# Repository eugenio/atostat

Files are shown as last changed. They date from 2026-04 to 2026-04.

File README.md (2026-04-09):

# atostat

A modular multichannel potentiostat with bipotentiostat capabilities, designed and built with [atopile](https://atopile.io).

## Key Specifications

- **Current range:** 10 nA to 1 A per channel (8 decades, switched-gain TIA)
- **Voltage range:** +/-2 V (bipolar DAC output via AD5693R + subtractor)
- **Channels:** 2 wired (architecture supports up to 8)
- **Bipotentiostat:** Yes (independent per-channel control)
- **Galvanic isolation:** 5 kV rated per channel (B0505S DC-DC + ISO1640 I2C + ISO7741 SPI/GPIO)
- **Modes:** Potentiostat and galvanostat (analog feedback path switching)
- **Connectivity:** WiFi, USB (ESP32-S3), CAN bus (SN65HVD230)
- **ADC:** Dual per channel -- ADS1256 (fast, 24-bit SPI) + NAU7802 (slow, 24-bit I2C)
- **DAC:** AD5693R (16-bit, I2C) with bipolar output stage
- **Sync:** Hardware trigger input, sync output, shared sync bus for multi-channel triggering

## Architecture Overview

The design is organized into three top-level modules wired together in `main.ato`:

**PowerSupply** -- Generates all voltage rails from a 5-12 V DC input.

- TPS63020 buck-boost converter (5 V analog rail)
- LDK220 LDO (3.3 V digital rail from 5 V)
- TPS60403 charge pump inverter (-5 V rail)

**ConnectivityGateway** -- Central coordinator built around an ESP32-S3.

- TCA9548A I2C multiplexer (8 channel fan-out)
- SPI bus with 74HC138 3-to-8 chip-select demux
- CAN bus transceiver (SN65HVD230) for multi-instrument sync
- External trigger input and sync pulse output

**PotentiostatChannel** (x2 wired) -- Fully isolated analog front end.

- Galvanic isolation: B0505S isolated DC-DC (custom no-Y-cap driver) + ISO1640 I2C isolator + ISO7741 SPI/GPIO isolator
- Control amplifier: AD8608 (quad rail-to-rail op-amp)
- Reference electrode buffer (high-impedance follower)
- Switched-gain TIA: MAX14778 analog mux selecting 8 gain resistor decades
- Mode switch: potentiostat/galvanostat feedback path selection
- Cell disconnect: TS5A22362 analog switch
- ADC interface: ADS1256 (SPI, fast sampling) + NAU7802 (I2C, precision)
- DAC waveform: AD5693R with bipolar subtractor output stage
- Per-channel RP2040 controller (placeholder -- see known issues)

## Module Listing

All custom modules live in `lib/`:

| File | Module | Description |
| ---- | --- | --- |
| `power_supply.ato` | PowerSupply | Multi-rail PSU (5 V, 3.3 V, -5 V) |
| `connectivity.ato` | ConnectivityGateway | ESP32-S3 + I2C mux + SPI CS demux + CAN |
| `channel_module.ato` | PotentiostatChannel | Complete isolated channel assembly |
| `control_amplifier.ato` | ControlAmplifier | AD8608-based control amp with CE drive |
| `re_buffer.ato` | REBuffer | High-impedance reference electrode buffer |
| `switched_gain_tia.ato` | SwitchedGainTIA | 8-decade gain TIA (MAX14778 mux) |
| `adc_interface.ato` | ADCInterface | Dual ADC (ADS1256 + NAU7802) |
| `dac_waveform.ato` | DACWaveform | AD5693R DAC with bipolar output |
| `mode_switch.ato` | ModeSwitch | Potentiostat/galvanostat feedback selector |
| `galvanic_isolator.ato` | GalvanicIsolator | B0505S + ISO1640 I2C isolation |
| `spi_isolator.ato` | SPIIsolator | ISO7741 SPI/GPIO isolation |
| `channel_controller.ato` | ChannelController | Per-channel RP2040 (placeholder) |
| `spi_cs_demux.ato` | SPIChipSelectDemux | 74HC138 3-to-8 CS demux |
| `can_bus.ato` | CANBus | SN65HVD230 CAN transceiver |
| `eis_excitation.ato` | EISExcitation | EIS sine excitation (stub) |
| `ads1256.ato` | ADS1256 | ADS1256 24-bit ADC driver |
| `ad8608.ato` | AD8608 | AD8608 quad op-amp driver |
| `iso7741.ato` | ISO7741 | ISO7741 digital isolator driver |
| `b0505s_no_ycap.ato` | B0505S_NoYcap | B0505S DC-DC without Y-cap (DRC fix) |
| `tps60403.ato` | TPS60403 | TPS60403 charge pump inverter driver |
| `ferrite_bead.ato` | FerriteBead | Murata BLM15AG601SN1D ferrite bead |

## Dependencies

All hardware dependencies are from the atopile registry (see `ato.yaml`):

- `atopile/ti-tps63020` -- Buck-boost converter
- `atopile/st-ldk220` -- LDO regulator
- `atopile/espressif-esp32-s3` -- WiFi/BLE MCU
- `atopile/ti-tca9548a` -- I2C multiplexer
- `atopile/ti-iso1640x` -- Isolated I2C
- `atopile/adi-ad5693r` -- 16-bit DAC
- `atopile/nuvoton-nau7802` -- 24-bit ADC (I2C)
- `atopile/ti-ts5a22362` -- Analog switch
- `atopile/raspberry-rp2040` -- Channel controller MCU
- `ruben-iteng/analog-devices-max14778` -- Analog mux (TIA gain)
- `ruben-iteng/connectors` -- Board connectors
- `ruben-iteng/dcdc-converters` -- Isolated DC-DC

## Building

Requires [atopile](https://atopile.io) >= 0.15.3.

```bash
ato build
```

The build compiles `main.ato:App`, runs all 18 build stages, and picks 189 components. Output goes to `build/`.

## Current Status

**V0.4** -- Two channels fully wired with galvanic isolation, SPI isolation, and CS demux. The build passes cleanly.

### Known Issues

- **RP2040 placeholder:** The per-channel RP2040 controller is a stub. Full integration is blocked by an upstream atopile issue with `has_single_electric_reference_shared` traits in isolated power domains ([atopile/atopile#1812](https://github.com/atopile/atopile/issues/1812)).
- **Tracking issue:** [eugenio/atostat#1](https://github.com/eugenio/atostat/issues/1)

See [docs/V0.4_ROADMAP.md](docs/V0.4_ROADMAP.md) for the full roadmap including resolved and open items.

## License

MIT -- see [LICENSE.txt](LICENSE.txt).

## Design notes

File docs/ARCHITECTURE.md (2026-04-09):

# atostat Architecture Overview

Modular multichannel potentiostat/bipotentiostat. Two independently isolated
channels, each capable of potentiostat and galvanostat modes. Current range
10 nA -- 100 mA full-scale, cell voltage +/-2.5 V.

Written in [atopile](https://atopile.io) hardware description language.

---

## 1. High-Level Block Diagram

```
                          +-------------------+
   5-12 V DC in --------->|   PowerSupply     |
                          |  TPS63020 buck-   |
                          |  boost -> 5 V     |
                          |  LDK220 LDO -> 3.3V
                          |  TPS60403 -> -5 V |
                          +---+---+---+-------+
                              |   |   |
               +--------------+   |   +--------------+
               |  5 V             | 3.3 V             |  5 V
               v                  v                   v
   +-----------+------+   +------+--------+   +------+-----------+
   | PotentiostatCh 0 |   | Connectivity  |   | PotentiostatCh 1 |
   | (isolated)       |   | Gateway       |   | (isolated)        |
   +------------------+   | (ESP32-S3)    |   +-------------------+
                          +---------------+

   Each channel receives host 5 V for its B0505S isolated DC-DC.
   The gateway runs on 3.3 V.
   Host 3.3 V also powers the SPI isolator host side on each channel.
```

---

## 2. Per-Channel Signal Flow

Each `PotentiostatChannel` contains the complete analog front-end on the
isolated side of a galvanic barrier.

```
                         ISOLATED SIDE
  ┌──────────────────────────────────────────────────────────────┐
  │                                                              │
  │  AD5693R DAC (I2C, 16-bit)                                  │
  │      |                                                       │
  │      | 0-5 V unipolar                                        │
  │      v                                                       │
  │  Switchable RC filter (1 kOhm + 100 nF, fc ~1.6 kHz)       │
  │      |                                                       │
  │      v                                                       │
  │  Bipolar subtractor (V_dac - V_ref = +/-2.5 V)              │
  │      |                                                       │
  │      v                                                       │
  │  Control Amplifier (AD8608 sect. A)                          │
  │      |  ^                                                    │
  │      |  | feedback (re_input)                                │
  │      |  |                                                    │
  │      |  ModeSwitch (TS5A22362 SPDT)                         │
  │      |    |potentiostat        |galvanostat                  │
  │      |    |                    |                              │
  │      |  RE Buffer            TIA output                      │
  │      |  (AD8608 sect. A)     (current_output)                │
  │      |    ^                                                  │
  │      |    |                                                  │
  │      v    |                                                  │
  │  CE ←[cell switch]← ctrl_amp    RE ──────→ RE Buffer        │
  │                                                              │
  │  WE ←[cell switch]→ TIA input                               │
  │                      (AD8608 sect. A)                        │
  │                      8-range switched gain                   │
  │                      (2x MAX14778 + TS5A22362 bank select)   │
  │                         |                                    │
  │                         v                                    │
  │               ┌─────────────────────┐                        │
  │               │ ADC Interface       │                        │
  │               │  CH1: I_cell (TIA)  │                        │
  │               │  CH2: V_cell (WE-RE)│                        │
  │               │                     │                        │
  │               │ Fast: ADS1256       │                        │
  │               │  24-bit, 30 kSPS    │                        │
  │               │  SPI to RP2040      │                        │
  │               │                     │                        │
  │               │ Slow: NAU7802       │                        │
  │               │  24-bit, 320 SPS    │                        │
  │               │  I2C to RP2040      │                        │
  │               └─────────────────────┘                        │
  │                                                              │
  │  RP2040 controller ← SPI to ADS1256, I2C to DAC + NAU7802   │
  │      | gain select GPIOs -> TIA mux address lines            │
  │      | cell_enable, mode_select GPIOs                        │
  └──────┼───────────────────────────────────────────────────────┘
         | isolated SPI (through ISO7741 SPI isolator)
         |
   ══════╪════ ISOLATION BARRIER ════════════════════════
         |
      HOST SIDE
```

### ADC signal routing

| ADC Channel | Positive Input | Negative Input | Measures |
|---|---|---|---|
| CH1 | TIA current_output | Isolated GND | Cell current |
| CH2 | WE potential (TIA Vg) | Buffered RE | Applied cell voltage (V_WE - V_RE) |

---

## 3. Isolation Boundary

Every channel has a galvanic isolation barrier implemented by `GalvanicIsolator`.

### Host side (non-isolated)

- ESP32-S3 gateway (WiFi, USB, CAN, trigger/sync)
- TCA9548A I2C mux (fallback path)
- SN74HC138 SPI CS demux
- PowerSupply rails: 5 V, 3.3 V, -5 V
- Host side of each ISO7741 SPI isolator (powered from host 3.3 V)

### Isolated side (per channel)

- B0505S 1 W isolated DC-DC (5 V host -> 5 V isolated)
- LDK220 LDO (5 V iso -> 3.3 V clean analog, AVDD)
- Pi-filter ferrite (3.3 V analog -> 3.3 V digital, DVDD)
- RP2040 real-time controller
- All analog front-end: DAC, control amp, RE buffer, mode switch, TIA, ADCs
- Cell disconnect switches (TS5A22362), electrode connections

### Signals crossing the barrier

| Signal | Direction | Isolator | Notes |
|---|---|---|---|
| SPI (SCLK, MOSI, CS) | Host -> Isolated | ISO7741 (SPI iso) | 3 of 4 channels A->B |
| SPI (MISO) | Isolated -> Host | ISO7741 (SPI iso) | 1 channel B->A |
| I2C (SDA, SCL) | Bidirectional | ISO1640 | Fallback path |
| GPIO out x3 | Host -> Isolated | ISO7741 (GPIO iso) | TIA gain select (legacy) |
| DRDY | Isolated -> Host | ISO7741 (GPIO iso) | ADS1256 data ready |
| Power | Host -> Isolated | B0505S DC-DC | 5 V, 1 W, no Y-cap  |

---

## 4. Communication Topology

### Primary: SPI (high-speed data path)

```
ESP32-S3  ──SPI bus──┬──[74HC138 CS demux]──CS[0]──[ISO7741]──RP2040 ch0
  GPIO IO10 = master CS    │                                     |
  GPIO IO21/38/39 = addr   ├──CS[1]──[ISO7741]──RP2040 ch1      |
                           ├──CS[2..7] (expansion)               |
                           :                                     |
                                                    RP2040 ──SPI0──> ADS1256
                                                    RP2040 ──I2C0──> DAC + NAU7802
```

The 74HC138 decoder is gated by the ESP32 master CS: when CS goes low the
addressed output goes low, selecting exactly one channel. Address is latched
before CS assertion. Supports up to 8 channels.

Each channel RP2040 uses two SPI peripherals:
- SPI1 (slave): host communication through ISO7741
- SPI0 (master): local ADS1256 fast ADC

### Fallback: I2C (low-speed, legacy)

```
ESP32-S3  ──I2C──> TCA9548A mux ──ch[0]──[ISO1640]──> isolated I2C bus ch0
                                  ──ch[1]──[ISO1640]──> isolated I2C bus ch1
                                  ──ch[2..7] (expansion)
```

The TCA9548A fans out the master I2C to 8 channels. Each channel's isolated
I2C connects to AD5693R DAC (addr 0x0C) and NAU7802 ADC (addr 0x2A) --
no per-channel address mux needed since the addresses differ.

### Synchronization

| Bus | IC | Purpose |
|---|---|---|
| CAN | SN65HVD230  | Multi-board synchronization, 1 Mbps |
| Sync bus | GPIO + 100R | Hardware trigger line, all channels |
| Trigger in | GPIO IO16 | External instrument trigger input |
| Sync out | GPIO IO17 + 100R | Sync pulse to external instruments |

---

## 5. Power Domains

### System-level rails (PowerSupply)

| Rail | Source | Voltage | Purpose |
|---|---|---|---|
| Host 5 V | TPS63020 buck-boost | 5.0 V +/- 3%  | Channel DC-DC input, op-amp supply |
| Host 3.3 V | LDK220 LDO from 5 V | 3.3 V +/- 3% | ESP32-S3, I2C mux, SPI CS demux, SPI iso host side |
| Host -5 V | TPS60403 charge pump  | -5.0 V (magnitude 4.5-5.5 V) | Negative op-amp rail (system-level) |

### Per-channel isolated rails (GalvanicIsolator)

| Rail | Source | Voltage | Purpose |
|---|---|---|---|
| Iso 5 V raw | B0505S DC-DC from host 5 V | 5.0 V nominal | Op-amp supply, charge pump input |
| Iso 3.3 V analog (AVDD) | LDK220 LDO from iso 5 V | 3.3 V +/- 3% | ADS1256 AVDD, NAU7802 |
| Iso 3.3 V digital (DVDD) | Pi-filter from AVDD | 3.3 V | RP2040, ISO7741 iso side, ISO1640 iso side |

The AVDD/DVDD separation uses a pi-filter (10 uF -- ferrite 600 Ohm@100 MHz -- 10 uF)
to prevent digital switching noise from reaching the ADC analog supply.

Note: Isolated -5 V rail for bipolar op-amp operation is planned but not yet
instantiated due to an atopile solver limitation with the TPS60403 inverted
power model.

---

## 6. Key Component Choices

| Component | Part | Why |
|---|---|-----|
| **Gateway MCU** | ESP32-S3 | WiFi + USB + BLE in a single module; sufficient GPIO for SPI master + CS demux address + CAN + sync. |
| **Channel MCU** | RP2040 | Dual-core for deterministic real-time measurement loop; PIO blocks enable precise SPI timing; low cost. |
| **Isolated DC-DC** | B0505S-1WR3 (no Y-cap) | 1 W isolated DC-DC in SIP-4; Y-cap removed to prevent common-mode leakage that degrades isolation for electrochemical cells. |
| **I2C isolator** | ISO1640 (TI) | Bidirectional I2C isolation with integrated pull-ups; automotive-grade (Q1 variant). |
| **SPI/GPIO isolator** | ISO7741 (TI) | 4-channel digital isolator, 3+1 directional split matches SPI topology (SCLK/MOSI/CS out, MISO in). |
| **SPI CS demux** | SN74HC138 | Classic 3-to-8 decoder; active-low outputs match SPI CS convention; gated by master CS for clean enable/disable. |
| **I2C mux** | TCA9548A | 8-channel I2C mux for fallback addressing; each channel gets its own isolated I2C segment. |
| **Control amp op-amp** | AD8608 (quad) | Rail-to-rail I/O, 10 MHz GBW, 0.065 uV/C drift, low noise (8 nV/rtHz); quad package shares across control amp, RE buffer, subtractor, TIA sections. |
| **Fast ADC** | ADS1256 | 24-bit delta-sigma, 30 kSPS, SPI; suitable for CV, SWV, DPV at scan rates up to ~1 V/s. |
| **Slow ADC** | NAU7802 | 24-bit, 320 SPS, I2C; low-power precision for OCP and long chronoamperometry experiments. |
| **DAC** | AD5693R | 16-bit, I2C, internal 2.5 V reference with 2x gain (0-5 V output); bipolar output achieved via external subtractor. |
| **TIA gain mux** | MAX14778 (dual 4:1) | Low on-resistance (< 10 Ohm), low charge injection analog mux; two units give 8 gain ranges spanning 7 decades. |
| **Cell disconnect / mode / filter / comp switches** | TS5A22362 | Dual SPDT analog switch, low Ron (~1 Ohm), rail-to-rail; used throughout for cell disconnect, mode select, filter bypass, and compensation network switching. |
| **Buck-boost (5 V)** | TPS63020 | Wide input 2-12 V to 5 V, 96% efficiency, 4 A switch current; handles both USB 5 V and barrel-jack inputs. |
| **LDO (3.3 V)** | LDK220 | Low noise (6.5 uVrms), high PSRR (>70 dB @ 100 kHz), 200 mA; used both system-level and per-channel for clean analog supply. |
| **Charge pump (-5 V)** | TPS60403 | Unregulated inverter, VIN -> -VIN; minimal external components (2 caps). |
| **RE buffer** | AD8608 section + 10 MOhm input R | Ultra-high input impedance prevents current draw from reference electrode; 10 MOhm limits fault current to sub-uA. Guard ring driver on section B. |

---

## 7. Module Inventory

| File | Module | Role |
|---|---|---|
| `main.ato` | `App` | Top-level: PSU, gateway, 2 channels, electrode connectors, trigger/sync |
| `lib/power_supply.ato` | `PowerSupply` | 5 V buck-boost, 3.3 V LDO, -5 V charge pump |
| `lib/connectivity.ato` | `ConnectivityGateway` | ESP32-S3, TCA9548A I2C mux, SPI CS demux, CAN, sync |
| `lib/channel_module.ato` | `PotentiostatChannel` | Full isolated channel: isolator + controller + AFE |
| `lib/galvanic_isolator.ato` | `GalvanicIsolator` | B0505S DC-DC, ISO1640 I2C iso, ISO7741 GPIO iso, AVDD/DVDD split |
| `lib/spi_isolator.ato` | `SPIIsolator` | ISO7741-based isolated SPI (SCLK/MOSI/CS out, MISO in) |
| `lib/channel_controller.ato` | `ChannelController` | RP2040 placeholder, GPIO mapping, SPI/I2C peripherals |
| `lib/control_amplifier.ato` | `ControlAmplifier` | Error amplifier driving CE, 3 switchable RC comp networks |
| `lib/re_buffer.ato` | `REBuffer` | Unity-gain follower for RE, guard ring driver |
| `lib/mode_switch.ato` | `ModeSwitch` | SPDT selecting RE buffer or TIA feedback (pot/galv mode) |
| `lib/switched_gain_tia.ato` | `SwitchedGainTIA` | 8-range TIA (10 nA -- 100 mA FS), 2x MAX14778 + bank switch |
| `lib/adc_interface.ato` | `ADCInterface` | Dual ADC: ADS1256 (SPI, fast) + NAU7802 (I2C, slow) |
| `lib/dac_waveform.ato` | `DACWaveform` | AD5693R + RC filter + bipolar subtractor (+/-2.5 V out) |
| `lib/spi_cs_demux.ato` | `SPIChipSelectDemux` | 74HC138 3-to-8 decoder for per-channel SPI CS |

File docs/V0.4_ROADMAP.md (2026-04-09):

# V0.4 Roadmap

## Build Blockers

- [x] Resolve B0505S Y-cap false short — custom `B0505S_NoYcap_driver` in `lib/b0505s_no_ycap.ato` omits the 270 pF anti-EMI Y-cap that bridges host/isolated GND, eliminating false DRC short detection
- [ ] Replace RP2040 placeholder with full `Raspberry_Pi_RP2040` module (blocked by atopile `has_single_electric_reference_shared` trait in isolated power domains — upstream issue)

## Component Quality

- [x] Replace auto-generated KiCad footprints/symbols with JLCPCB-sourced ones (ADS1256 C28186, ISO7741 C179463, SN65HVD230 C12084) — already present in `parts/`
- [x] Replace ferrite bead resistor placeholders with real Murata BLM15AG601SN1D (LCSC C76884) `Inductor` instances in `galvanic_isolator.ato` and `connectivity.ato`
- [x] Replace ISO7741 placeholder in `galvanic_isolator.ato` and `spi_isolator.ato` with real `ISO7741_driver` from `lib/iso7741.ato` — unblocked by B0505S Y-cap fix

## Architectural

- [x] Add per-channel SPI chip-select demux — `SPIChipSelectDemux` in `lib/spi_cs_demux.ato` using TI SN74HC138PWR (LCSC C157527), integrated into `ConnectivityGateway` with 3 address GPIOs and 8 active-low CS outputs
- [ ] Add OTA firmware update path for per-channel RP2040 (SWD or USB bootloader via isolator)
- [ ] Evaluate replacing B0505S with higher-power isolated DC-DC — RECOM RB-0505D out of stock on JLCPCB ($15+), not viable currently. Re-evaluate when RP2040 power budget is known.

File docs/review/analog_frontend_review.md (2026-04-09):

# Analog Front-End Design Review

## P0 Blockers (Must Fix)

### 1. No Op-Amp ICs
**All op-amp modules** have placeholder interfaces only -- no actual IC.
- **Fix**: Create AD8608 (quad CMOS, 1 pA bias, R-R I/O) atopile package. Instantiate in control_amplifier, re_buffer, switched_gain_tia (3 of 4 sections). For TIA 10nA range, add LMP7721 (3 fA bias) option.

### 2. No Cell Disconnect Switch
No mechanism to disconnect the cell during power-up/idle/power-down. Safety hazard.
- **Fix**: Add DPDT relay on CE and WE lines in `channel_module.ato`. Route control through isolator.

### 3. CD74HC4067 Unsuitable for TIA Feedback
- R_on: 70-100 ohm (350% error on 20 ohm range)
- Leakage: 100 nA at 25C (10x full-scale at 10 nA range)
- Cannot pass negative voltages (CMOS logic-level mux)
- **Fix**: Replace with MAX14778 (+-25V, low R_on, low leakage) for ranges 0-5. Discrete low-R_on switches for 200/20 ohm ranges. Latching relays for 100M/20M ranges.

### 4. DAC Output is Unipolar
AD5693R outputs 0 to 5V only. Cannot apply negative potentials.
- **Fix**: Add subtractor circuit (precision diff amp) after DAC to produce +-Vref output, or use virtual-ground-at-midscale approach.

### 5. No Bipolar Supply
Isolated side is single-ended 5V. Op-amps need +-5V for bipolar operation.
- **Fix**: Add inverting charge pump (LM27761 or TPS60403) on isolated side to generate -5V from +5V.

## P1 Major Issues

| # | Issue | File | Fix |
|---|---|---|-----|
| 6 | TIA missing non-inverting input interface | switched_gain_tia.ato | Add opamp_noninverting_in, connect to ground reference |
| 7 | TIA gain_select lines dangling (not connected to controller) | channel_module.ato | Route through GPIO expander (PCA9535) on isolated I2C |
| 8 | NAU7802 too slow (320 SPS max) for CV | adc_interface.ato | Replace with ADS1256 (30 kSPS, SPI) or add fast ADC path |
| 9 | No galvanostat mode | channel_module.ato | Add SPDT switch selecting RE buffer vs TIA output as control amp feedback |
| 10 | CE output tapped before snubber | control_amplifier.ato | Move ce_output connection to after snubber resistor |
| 11 | RE buffer feedback loop incomplete | re_buffer.ato | Wire opamp_output to opamp_inverting_in inside module |

## P2 Moderate Issues

| # | Issue | Fix |
|---|---|-----|
| 12 | ADC voltage channel reads V_RE (redundant) | Measure V_WE vs V_RE instead |
| 13 | No TIA input protection | Add BAT54S Schottky clamp diodes |
| 14 | No guard ring driver | Add unity-gain buffer for guard net |
| 15 | DAC 1.6 kHz filter limits fast techniques | Make switchable |
| 16 | No EIS capability | Add AC excitation path (DDS + summing network) |

## P3 Nice-to-Have

| # | Issue | Fix |
|---|---|-----|
| 17 | No CE voltage clamp | Add TVS diode (SMBJ5.0A) |
| 18 | Fixed compensation (200 Hz) | Make switchable for different cell types |

## Noise Analysis Summary
- 10 nA range (100 MOhm): 0.24 pA RMS noise floor at 340 Hz BW -- acceptable
- NAU7802: ~20 ENOB at 320 SPS, adequate resolution but too slow
- 1 kohm ADC protection resistors: acceptable (51 nV RMS additional noise)
- DAC 1.6 kHz filter: OK for standard CV, limits fast techniques

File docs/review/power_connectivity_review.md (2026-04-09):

# Power, Isolation & Connectivity Architecture Review

## P0 Blockers

### 1. No Bipolar Supply (shared with analog review)
Single 5V rail cannot produce negative potentials. Cannot do reduction chemistry.
- **Fix**: Add TPS60403 charge pump (-5V, 60 mA) or replace B0505S with dual-output isolated converter (Murata MEE3S0505SC: +5V/-5V). Virtual ground at 2.5V is a cheaper workaround but halves dynamic range.

### 2. No Post-Isolation Analog Filtering
B0505S switching ripple (50-100 mV_pp at 100-300 kHz) goes directly to ADC AVDD. Limits effective resolution to ~14 bits, wasting the NAU7802's 24-bit capability.
- **Fix**: Add low-noise LDO (TPS7A4700 or LDK220) between B0505S and analog components. PSRR >70 dB at 100 kHz reduces ripple to <30 uV.

### 3. TIA Gain Select Lines Floating (shared with analog review)
No connection from gain_select[4] to any controller. Cannot change current range.
- **Fix**: Add ISO7741 quad digital isolator + GPIO, or PCA9535 I2C GPIO expander on isolated bus.

## P1 Major Issues

| # | Issue | Fix |
|---|---|-----|
| 4 | Per-channel TCA9548A unnecessary (DAC 0x0C, ADC 0x2A don't conflict) | Remove, save $1.50 + 6 mA + 50 us latency per channel |
| 5 | NAU7802 DRDY not routed through isolation | Add digital isolator channel for interrupt, saves ~30% I2C bandwidth |
| 6 | No external trigger/sync I/O | Add BNC connectors + optocoupler for lab instrument sync |
| 7 | No AVDD/DVDD separation on isolated side | Add ferrite bead + decoupling between analog and digital power |
| 8 | WiFi TX bursts cause 3.3V rail dips | Add ferrite + 100 uF or dedicated LDO for ESP32-S3 |

## P2 Scalability & Performance

| # | Issue | Fix |
|---|---|-----|
| 9 | I2C bus bottleneck: max ~56 SPS/channel at 8 channels | Replace NAU7802 with SPI ADC (ADS1256, 30 kSPS) + SPI isolator |
| 10 | No per-channel real-time controller | Add RP2040 per channel (isolated side) for autonomous control loop |
| 11 | B0505S (1W) insufficient for high-current ranges | Upgrade to 2-3W converter, or bypass TIA for >10 mA |
| 12 | No multi-channel sync mechanism | Add CAN bus or hardware trigger line for simultaneous start |

## P3 Nice-to-Have

| # | Issue | Fix |
|---|---|-----|
| 13 | I2C limited to 400 kHz | Add LTC4311 accelerator for 1 MHz Fast-mode Plus |
| 14 | No power-good monitoring | Add TPS3839 voltage supervisor per rail |
| 15 | Per-channel TCA9548A overkill | Replace with LTC4316 address translator if needed |

## Power Budget Analysis (per channel)

| Component | Typical | Peak |
|---|---|---|
| ADC (NAU7802) | 2.4 mA | 5 mA |
| DAC (AD5693R) | 0.5 mA | 1.5 mA |
| Control amp op-amp | 1.5 mA | 15-30 mA (driving CE) |
| RE buffer op-amp | 1 mA | 2 mA |
| TIA op-amp | 1.5 mA | 5 mA |
| Mux + isolator | 3.5 mA | 5.5 mA |
| **Total** | **~10 mA (50 mW)** | **~60 mA (300 mW)** |

At high-current range (100 mA cell current): CE driver alone = 500 mW, exceeding B0505S 1W budget.

## Bus Throughput Analysis

8 channels at 400 kHz I2C:
- Per-channel cycle: ~275 us (switch + ADC read + DAC write)
- 8 channels sequential: 2.2 ms = **454 Hz max scan rate total**
- Per channel at 8 active: **~56 SPS** (inadequate for CV)

With SPI ADC at 10 MHz: per-channel read = 2.4 us, enabling 30 kSPS per channel.

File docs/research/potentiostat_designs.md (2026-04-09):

# Open-Source Potentiostat Design Research

## Atopile Packages Available

### DACs
| Package | Resolution | Interface | Notes |
| --- | --- | --- | --- |
| `adi-ad5693r` | 16-bit | I2C | Good for voltage control |
| `microchip-mcp4725` | 12-bit | I2C | Single channel |
| `microchip-mcp4728` | 12-bit | I2C | 4-channel |
| `ti-dac6578` / `ti-dac7578` | 12-bit | I2C | 8-channel |

### ADCs
| Package | Resolution | Interface | Notes |
| --- | --- | --- | --- |
| `nuvoton-nau7802` | **24-bit** | I2C | 2-ch differential, PGA, 23 ENOB -- **BEST FIT** |
| `microchip-mcp3421` | 18-bit | I2C | Single-ch, differential, 2.048V ref |
| `ti-ads1115` | 16-bit | I2C | 4-ch, PGA, delta-sigma |
| `ti-ads7830` | 8-bit | I2C | 8-ch, housekeeping only |

### Current/Power Sensing
| Package | Notes |
| --- | --- |
| `ti-ina228` | 85V, 20-bit I2C power monitor |
| `ti-ina232` | 48V, 16-bit |
| `ti-ina237` / `ti-ina238` | 85V, 16-bit |
| `ti-ina3221` | Triple-channel |
| `ti-ina185a1` | 26V bi-directional current sense amp |

### Analog Switches / Muxes
| Package | Notes |
| --- | --- |
| `ruben-iteng/analog-devices-max14778` | **Dual 4:1 mux, +-25V above/below rails** -- BEST for TIA gain switching |
| `ti-ts5a22362` | DPDT analog switch, low R_on |
| `ti-cd74hc4067sm` | 16-channel analog mux/demux |
| `ruben-iteng/logic (SN74CB3Q3251)` | 8:1 FET mux, fast, low-voltage |

### I2C Infrastructure
| Package | Notes |
| --- | --- |
| `ti-tca9548a` | 8-ch I2C mux (multichannel addressing) |
| `ti-iso1640x` | I2C isolator (channel isolation) |
| `adi-ltc4311` | I2C accelerator |
| `adi-ltc4316` | I2C address translator |

### MCUs
| Package | Notes |
| --- | --- |
| `espressif-esp32-s3` | WiFi/BLE |
| `raspberry-rp2040` | Dual-core Cortex-M0+ |
| `st-stm32h723` | High-perf Cortex-M7 |

### Power
| Package | Notes |
| --- | --- |
| `ti-tps63020` | Buck-boost, 1.8-5.5V in, 3A -- battery operation |
| `ruben-iteng/dcdc-converters (b0505s1wr3)` | **Isolated 5V-to-5V, 1W** -- per-channel isolation |
| `st-ldk220` | Adjustable LDO, 200 mA, low noise |
| `ti-tps82130` | 17V MicroSiP module, 2A, integrated inductor |
| `ti-tps563201` | 3A sync buck, SOT-23-6 |

### Additional Useful Packages
| Package | Notes |
| --- | --- |
| `ti-drv135` | Balanced line driver, bipolar supply (+-10V), force/sense pins |
| `ruben-iteng/connectors` | **Banana plugs** for electrode connections, QWIIC |
| `ruben-iteng/logic (ISO1540)` | I2C isolator, bidirectional |
| `ruben-iteng/relays` | Mechanical relays for high-current switching |
| `atopile/generics` | Op-amp topologies (VoltageFollower, InvertingAmplifier, DiffAmp, InstrumentationAmplifier, Integrator), R/C/L, VDiv, LPF, interfaces (Power, FloatPower, I2C, SPI, Analog, DiffPair) |
| `atopile/cell-sim` | 16-ch isolated cell simulator, closest architecture reference |

### Key Gaps -- Packages We Must Create
1. **Precision op-amps** -- No OPA188, OPA2277, AD8628, LMP7721, OPA129 etc. Must subclass generic `Opamp`
2. **Voltage references** -- No REF5025, LT1009, ADR4525 etc.
3. **High-res SPI ADCs** -- No ADS1256 (24-bit SPI), ADS1263 (32-bit), AD7177
4. **Potentiostat AFE ICs** -- No AD5940/AD5941, ADuCM355, LMP91000
5. **Bipolar/negative supply generators** -- No charge pump or inverting converter for -2V to -5V rail
6. **Digital potentiometers** -- `maxim-ds1841` and `maxim-ds3502` exist but unverified for this use

---

## Open-Source Potentiostat Projects

### Tier 1: Best Architecture References

#### tdstat (Thomas Dobbelaere)
- **Repo**: https://github.com/thomasdob/tdstat
- **ICs**: MAX5217 (16-bit DAC), MCP3422 (18-bit ADC), TL431 ref, PIC16F1459
- **Architecture**: Classic 3-electrode with relay-switched TIA feedback resistors (4 ranges)
- **Range**: +-6.144V measurable, ~$50 BOM
- **Key insight**: Relay-switched TIA gain resistor approach, detailed circuit wiki
- **Relevance**: Directly adaptable topology, extend to 8 decades

#### MYSTAT (Matthew Yates)
- **Repo**: https://github.com/matthew-yates/MYSTAT
- **Range**: +-200 mA, +-12V
- **Published**: HardwareX (peer-reviewed)
- **Key insight**: Potentiostat AND galvanostat modes
- **Relevance**: Best ref for higher current ranges, KiCad-based

#### DStat (University of Toronto)
- **Paper**: https://journals.plos.org/plosone/article?id=10.1371/journal.pone.0140349
- **Key feature**: Picoampere current measurement, USB-powered
- **Relevance**: Best ref for low-noise nA measurement path

#### Rodeostat (IO Rodeo)
- **Repo**: https://github.com/iorodeo/potentiostat
- **ICs**: Teensy 3.2, 12-bit DAC, 16-bit ADC
- **Range**: +-1/10/100/1000 uA (4 ranges), +-1/2/5/10V
- **Key insight**: JSON API, expansion headers, modular
- **Relevance**: Software API model, 4-range architecture

#### PassStat
- **Paper**: https://www.hardware-x.com/article/S2468-0672(22)00035-9/fulltext
- **Performance**: <1 pA noise, 8000 V/s scan rate, ohmic drop compensation
- **Cost**: ~10 EUR analog board + Teensy
- **Relevance**: Best noise performance of any open-source design

### Tier 2: Integrated AFE Approach (AD5940/AD5941)

#### FreiStat-IoT (University of Freiburg)
- **Repo**: https://github.com/IMTEK-FreiStat/FreiStat-IoT
- **ICs**: AD5941 + Adafruit Feather M0 WiFi
- **Features**: CV, LSV, amperometry, EIS
- **Published**: Analytical Chemistry (2023)
- **Relevance**: Demonstrates AD5941 as per-channel AFE

#### HunStat2
- **Repo**: https://github.com/hunstat2/HunStat2
- **ICs**: AD5941 + XIAO RP2040
- **Cost**: ~$30, <1 hour assembly
- **Relevance**: Simplest AD5941 design reference

#### ACEstat
- **Paper**: ACS Analytical Chemistry 2022
- **ICs**: ADuCM355 (AD5940 AFE + ARM Cortex-M3 on one chip)
- **Relevance**: Per-channel autonomous measurement node concept

### Tier 3: Specialized

| Project | Key Feature | Relevance |
| --- | --- | --- |
| CheapStat | Pioneer open-source potentiostat, ~$80 | Educational baseline |
| KickStat | LMP91000 coin-sized, 4.5 nA LOD | Integrated IC approach (too limited) |
| HELPStat | Handheld EIS (200kHz-0.15Hz), BLE | Most recent (2024) with onboard EIS fitting |
| NanoStat | ESP32, 2 ICs total, web UI, <$25 | Minimal viable potentiostat |
| PSoC-Stat | Cypress PSoC 5LP programmable analog | Interesting but platform-locked |
| PocketEC | Platform-agnostic app, multi-AFE support | Software architecture reference |

### Tier 4: High-Performance DAQ

#### Open COVG DAQ
- **Repo**: https://github.com/lucask07/open_covg_daq_pcb
- **ICs**: 4x AD7961 (16-bit 5 MSPS), ADS8686, 6x AD5453, OpalKelly FPGA
- **Key insight**: Standardized HDMI daughter-card interface, <2 us feedback
- **Relevance**: Modular daughter-card concept applicable to multichannel

### Multichannel Potentiostat Array (PLOS ONE 2021)
- **Paper**: https://pmc.ncbi.nlm.nih.gov/articles/PMC8445456/
- **Architecture**: Stackable boards, 8-64 channels at ~$8/channel
- **Range**: +-1.5 uA per channel (low-current only)
- **Relevance**: Key reference for stackable multichannel architecture

---

## Key ICs for Our Design

| IC | Type | Key Specs | Role |
| --- | --- | --- | --- |
| AD5940/AD5941 | Electrochemical AFE | Dual excitation, potentiostat+EIS, sequencer | Per-channel low-current AFE |
| ADuCM355 | AFE + MCU | AD5940-class + ARM Cortex-M3 | Per-channel autonomous node |
| AD8608 | Quad CMOS op-amp | R-R I/O, 1 pA bias, low noise | RE buffer, TIA, control amp |
| MAX9913 | Precision op-amp | Femtoamp input bias | Ultra-low-current TIA (nA) |
| OPA2277 | Dual precision op-amp | 10 uV offset, 0.1 uV/C drift | Differential voltage measurement |
| ADS1256 | 24-bit delta-sigma ADC | 30 kSPS, PGA 1-64x | Per-channel digitization |
| LTC2500-32 | 32-bit SAR ADC | 148 dB dynamic range | Calibration reference |
| MAX5217 | 16-bit DAC | SPI, low-glitch | Waveform generation |
| LMP91000 | Integrated potentiostat | I2C, programmable TIA | Too limited for our specs |

---

## Analog Design Patterns

### Control Amplifier (CE Driver)
- Inverting config: RE feedback on inv input, V_set on non-inv
- Cell impedance (Cdl, Rs, Rct) enters feedback loop -- stability critical
- Include RC compensation (tdstat: R21/C7 at 200 Hz rolloff + snubber R9/C8)
- Consider programmable compensation for different cell types

### Electrometer / RE Buffer
- Unity-gain, zero current draw from RE
- Must have GOhm-TOhm input impedance, pA-or-less bias current
- JFET/CMOS input mandatory: AD8608 (1 pA typ), OPA2277

### Switched-Gain TIA (WE Current Measurement)
- V_out = -I_cell x R_f
- 8 decades (10 nA to 1 A) requires ~8 feedback resistors:
  - 200 MOhm, 20 MOhm, 2 MOhm, 200 kOhm, 20 kOhm, 2 kOhm, 200 Ohm, 20 Ohm
- Use analog switches in feedback path (TS5A22362 already in atopile)
- Noise-critical at highest gain (200 MOhm): thermal noise + op-amp input noise
- Power-critical at lowest gain (20 Ohm): dissipation + op-amp output current

### Guard Rings (nA-Level Measurement)
- Surround high-Z traces with driven guard at same potential
- Both PCB sides, continuous rectangles, no gaps
- For TIA input: guard driven by virtual ground
- Layout concern in KiCad post-atopile netlist generation

### Bipotentiostat Architecture
- Two WE channels sharing one CE driver + RE buffer
- Each WE has independent TIA, DAC (potential offset), ADC
- Cross-talk prevention: careful routing, differential measurement
- Maps cleanly to modular per-channel design

### Multichannel Architecture Options
1. **Independent channels**: Each channel = complete potentiostat (CE, RE, WE). No crosstalk.
2. **Shared CE/RE, multiple WEs**: One control amp, one RE buffer, multiple TIA channels. Requires galvanic isolation.
3. **Multiplexed**: One potentiostat, analog mux switches cells. Not simultaneous.

**Recommended**: Hybrid -- independent isolated channel modules that CAN share CE/RE for bipotentiostat mode.

---

## Recommended Architecture

### Hybrid Approach
- **AD5941 as per-channel low-current AFE** (10 nA to ~100 uA) with free EIS
- **Discrete op-amp circuitry** for high-current range (100 uA to 1 A)
- **Galvanic isolation** per channel (isolated DC-DC + digital isolators)
- **Central controller** (STM32H7 or RP2040) coordinates via isolated SPI

### Atopile Modules to Create
1. `control-amplifier` -- CE driver with programmable compensation
2. `re-buffer` -- High-impedance RE voltage follower
3. `switched-gain-tia` -- 8-range TIA with analog switch selection
4. `current-range-selector` -- Switch bank + logic for auto-ranging
5. `adc-interface` -- 24-bit ADC with PGA
6. `dac-waveform-gen` -- 16-bit DAC for cell voltage control
7. `channel-module` -- Complete single-WE potentiostat channel
8. `bipotentiostat-controller` -- Shared CE/RE + dual WE coordination
9. `galvanic-isolator` -- Power + signal isolation per channel
10. `power-supply` -- Bipolar rails (+-2V minimum, likely +-5V internal)
11. `channel-controller` -- Per-channel MCU with Ethernet/USB/WiFi
12. `backplane-comms` -- Inter-channel bus + host interface

---

## Connectivity & Software Architecture

### Requirement
Each channel or bipotentiostat pair must be individually readable and controllable via
Ethernet, USB, or WiFi. The software must be scriptable and have a polished GUI.

### Hardware Connectivity Options

#### Option A: Per-Channel MCU with Network Stack (Recommended)
- Each channel board carries an ESP32-S3 (WiFi+USB) or W5500/W5100S (Ethernet)
- Each channel gets its own IP address or USB endpoint
- Channels are independently discoverable via mDNS/Zeroconf
- Central host aggregates channels but is not required for single-channel use
- **Pros**: True independence, any channel works standalone, natural scaling
- **Cons**: Higher per-channel BOM cost (~$3-5 for ESP32-S3)

#### Option B: Central Controller with Per-Channel Addressing
- Single powerful MCU/SBC (STM32H7, RP2040+W5500, or RPi Pico W) per chassis
- Internal SPI/I2C bus to channel analog boards
- Host exposes per-channel API endpoints via multiplexed addressing
- **Pros**: Lower per-channel cost, simpler channel boards
- **Cons**: Single point of failure, limited by bus bandwidth for many channels

#### Option C: Hybrid (Best of Both)
- Each channel has a lightweight MCU (RP2040) for real-time analog control
- A central gateway MCU/SBC (ESP32-S3 or RPi) provides Ethernet/WiFi/USB
- Internal bus (SPI or CAN) between gateway and channel MCUs
- Gateway exposes per-channel REST/WebSocket/SCPI endpoints
- **Pros**: Real-time performance on channel + network flexibility on gateway
- **Cons**: Two MCU types to firmware

### MCU Candidates (atopile packages available)

| MCU | Package | Ethernet | WiFi | USB | Notes |
| --- | --- | --- | --- | --- | --- |
| ESP32-S3 | `espressif-esp32-s3` | Via W5500 | Built-in | USB-OTG | Best WiFi option |
| RP2040 | `raspberry-rp2040` | Via W5500 | No | USB 1.1 | Best for real-time analog control |
| STM32H723 | `st-stm32h723` | Built-in MAC | No | USB-OTG | Best for Ethernet-native, high perf |
| ESP32-C3 | `espressif-esp32-c3` | No | Built-in | USB-JTAG | Low-cost WiFi option |

### Software Stack

```
+-----------------------------------------------+
|              Polished GUI (Desktop/Web)        |
|  PyQt6 / Electron / SvelteKit                 |
|  - Per-channel dashboard with live plots       |
|  - Experiment builder (drag-and-drop)          |
|  - Data export (CSV, HDF5, MDAT)              |
+-----------------------------------------------+
|              Scripting Layer                    |
|  Python SDK (atostat-py)                       |
|  - channel = Atostat.connect("192.168.1.10")  |
|  - channel.set_potential(0.5)                  |
|  - data = channel.run_cv(-0.5, 0.5, 0.1)     |
|  - Jupyter notebook integration               |
+-----------------------------------------------+
|              Protocol Layer                     |
|  REST API / WebSocket / SCPI over TCP          |
|  - GET /channels/{id}/status                   |
|  - POST /channels/{id}/experiment              |
|  - WS /channels/{id}/stream (real-time data)   |
|  - SCPI: :CHANnel1:POTential 0.5              |
+-----------------------------------------------+
|              Firmware                           |
|  Per-channel MCU (ESP-IDF / RP2040 SDK)        |
|  - Real-time control loop (1-100 kHz)          |
|  - Auto-ranging state machine                  |
|  - Data buffering + streaming                  |
|  - mDNS/Zeroconf discovery                     |
+-----------------------------------------------+
```

### Software Reference Projects
| Project | Approach | Relevance |
| --- | --- | --- |
| Rodeostat | JSON API over USB, Python lib, web GUI | API design model |
| FreiStat-IoT | WiFi + cloud, Arduino firmware | IoT pattern |
| PocketEC/Voyager | Multi-AFE platform-agnostic app | Software abstraction |
| NanoStat | Self-hosted web UI on ESP32 | Embedded web server |
| HELPStat | BLE + standalone, onboard fitting | Edge computing |
| EmStat Pico | MethodSCRIPT scripting language | Domain-specific scripting |

### Key Software Design Decisions
1. **Protocol**: REST + WebSocket for modern tooling; optional SCPI for lab integration
2. **Discovery**: mDNS (e.g., `channel-01.atostat.local`) for zero-config networking
3. **Scripting**: Python SDK as primary, with Jupyter integration for interactive experiments
4. **GUI**: Web-based (SvelteKit or similar) served from gateway, or desktop PyQt6
5. **Data format**: Streaming via WebSocket for real-time plots; HDF5/CSV for archival
6. **Firmware**: FreeRTOS on ESP32-S3 or bare-metal on RP2040 for deterministic timing
7. **Calibration**: Per-channel calibration data stored in flash, queryable via API

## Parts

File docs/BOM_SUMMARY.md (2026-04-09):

# Atostat Bill of Materials Summary

Build configuration: 2 channels (from `main.ato:App`).
Total component count: ~189 (from ato build output).

---

## 1. Key ICs

### System-Level ICs (1 per system)

| Part Number | Function | Package | Qty | Notes |
|---|---|---|---|---|
| ESP32-S3 | WiFi/USB gateway MCU | QFN-56 | 1 | atopile registry `atopile/espressif-esp32-s3 v0.3.0` |
| TCA9548A | I2C 8-channel multiplexer | TSSOP-24 | 1 | atopile registry `atopile/ti-tca9548a v0.2.0` |
| SN65HVD230 | CAN bus transceiver (1 Mbps) | SOIC-8 | 1 | Local package `parts/Texas_Instruments_SN65HVD230DR` |
| SN74HC138 | 3-to-8 SPI CS demux | TSSOP-16 | 1 | Local package `parts/Texas_Instruments_SN74HC138PWR` |
| TPS63020 | Buck-boost 5V regulator | QFN-14 | 1 | atopile registry `atopile/ti-tps63020 v0.4.0` |
| LDK220 | 3.3V LDO (system rail) | SOT-23-5 | 1 | atopile registry `atopile/st-ldk220 v0.3.0` |
| TPS60403 | Charge pump inverter (-5V) | SOT-23-5 | 1 | Local package `parts/Texas_Instruments_TPS60403DBVR` |

### Per-Channel ICs (multiply by number of channels)

| Part Number | Function | Package | Qty/Ch | Notes |
|---|---|---|---|---|
| RP2040 | Per-channel real-time controller | QFN-56 | 1 | Placeholder (`has_part_removed` trait); atopile registry `atopile/raspberry-rp2040 v0.2.5` |
| ADS1256 | Fast 24-bit SPI ADC (30 kSPS) | SSOP-28 | 1 | Local package `parts/Texas_Instruments_ADS1256IDBR` |
| NAU7802 | Slow 24-bit I2C ADC (320 SPS) | SOP-16 | 1 | atopile registry `atopile/nuvoton-nau7802 v0.4.0` |
| AD5693R | 16-bit I2C DAC | MSOP-10 | 1 | atopile registry `atopile/adi-ad5693r v0.2.3` |
| AD8608 | Quad precision CMOS op-amp | TSSOP-14 | 4 | `parts/Analog_Devices_AD8608ARUZ`; used in: TIA (x1), control amp (x1), RE buffer (x1), DAC subtractor (x1) |
| MAX14778 | Dual 4:1 analog mux (TIA gain) | TSSOP-16 | 2 | atopile registry `ruben-iteng/analog-devices-max14778 v0.1.2`; mux A (ranges 0-3) + mux B (ranges 4-7) |
| ISO7741 | Quad digital isolator (5 kV) | SSOP-16 | 2 | `parts/Texas_Instruments_ISO7741DBQR`; 1x GPIO isolator + 1x SPI isolator |
| ISO1640 | I2C digital isolator | SOIC-8 | 1 | atopile registry `atopile/ti-iso1640x v0.3.0` |
| B0505S-1WR3 | 5V-5V isolated DC-DC (1W) | SIP-4 | 1 | atopile registry `ruben-iteng/dcdc-converters v0.2.2`; Y-cap removed variant |
| LDK220 | 3.3V LDO (isolated analog) | SOT-23-5 | 1 | atopile registry `atopile/st-ldk220 v0.3.0`; post-isolation clean supply |
| TS5A22362 | Dual SPDT analog switch | VSSOP-8 | 5 | atopile registry `atopile/ti-ts5a22362 v0.2.1`; cell disconnect (x1), mode switch (x1), TIA bank select (x1), control amp comp (x2) |
| CD74HC4067 | 16:1 analog mux | TSSOP-24 | 0 | atopile registry `atopile/ti-cd74hc4067sm v0.1.1`; listed in deps but **not instantiated** in current design (TIA uses MAX14778 instead) |

### IC Count Summary (2-channel build)

| Category | Count |
|---|---|
| System-level ICs | 7 |
| Per-channel ICs (x2) | 38 (19 per channel) |
| **Total ICs** | **45** |

Note: RP2040 has `has_part_removed` trait (placeholder). The physical RP2040 module (crystal, flash, decoupling) is intended as a daughter-board or will be resolved when atopile trait issues are fixed.

---

## 2. Passive Components Estimate

Counted from .ato source files. Excludes passives internal to registry packages (ESP32-S3, TCA9548A, etc. may bring their own).

### Per-Channel Passives

| Module | Resistors | Capacitors | Inductors/Ferrites |
|---|---|---|---|
| SwitchedGainTIA | 13 | 8 | 0 |
| ControlAmplifier | 5 | 6 | 0 |
| REBuffer | 1 | 3 | 0 |
| DACWaveform | 6 | 2 | 0 |
| ADCInterface | 4 | 0 | 0 |
| ADS1256 driver | 7 | 3 | 0 |
| AD8608 (x4) | 0 | 8 | 0 |
| ISO7741 (x2) | 4 | 4 | 0 |
| GalvanicIsolator | 0 | 8 | 2 |
| B0505S driver | 0 | 3 | 2 |
| ModeSwitch | 1 | 0 | 0 |
| ChannelController | 1 | 1 | 0 |
| ChannelModule (top) | 0 | 2 | 0 |
| **Per-channel total** | **~42** | **~48** | **~4** |

### System-Level Passives

| Module | Resistors | Capacitors | Inductors/Ferrites |
|---|---|---|---|
| ConnectivityGateway | 3 | 3 | 1 |
| CANBus | 2 | 1 | 0 |
| SPIChipSelectDemux | 0 | 1 | 0 |
| PowerSupply | 0 | 6 | 0 |
| TPS60403 driver | 0 | 3 | 0 |
| **System total** | **~5** | **~14** | **~1** |

### Grand Total Passives (2-channel build)

| Type | Count |
|---|---|
| Resistors | ~89 |
| Capacitors | ~110 |
| Inductors/Ferrites | ~9 |
| **Total passives** | **~208** |

Note: The 189 total from the ato build includes ICs + passives and may differ because registry packages resolve to specific picked parts. Some passives may be merged by the solver if they share the same net and value.

---

## 3. JLCPCB Assembly Notes

### JLCPCB Basic Library (low/no extra fee)

These parts are commonly stocked and incur no extended-part surcharge:

- 0402/0603/0805 resistors (all standard E96 values used)
- 0402/0603/0805 ceramic capacitors (100nF, 1uF, 10uF, 100uF, 4.7pF, 47pF, 470pF, 1nF, 4.7nF, 2.2uF, 22uF)
- Ferrite beads: Murata BLM15AG601SN1D (LCSC C76884) -- basic
- SN65HVD230DR (CAN transceiver) -- basic
- SN74HC138PWR (3-to-8 decoder) -- basic
- LDK220M-R (SOT-23-5 LDO) -- basic

### JLCPCB Extended Library (per-part surcharge applies)

These parts require the extended library fee (~$3 per unique extended part):

| Part | Reason |
|---|---|
| ESP32-S3-WROOM-1 | Specialty MCU module |
| RP2040 | Specialty MCU (placeholder, not placed yet) |
| ADS1256IDBR | Precision ADC, specialty |
| NAU7802SGI | 24-bit ADC, specialty |
| AD5693RACPZ | 16-bit DAC, specialty |
| AD8608ARUZ | Quad precision op-amp, specialty |
| MAX14778ETE+ | Dual 4:1 analog mux, specialty |
| ISO7741DBQR | Quad digital isolator, specialty |
| ISO1640QDWRQ1 | I2C isolator, specialty |
| TPS63020DSJR | Buck-boost regulator, specialty |
| TPS60403DBVR | Charge pump, may be basic depending on stock |
| B0505S-1WR3 | Isolated DC-DC, specialty (may need manual placement) |
| TS5A22362DGSR | Dual SPDT switch, extended |
| CD74HC4067SM96 | 16:1 mux, extended (not used in current design) |

### Assembly Considerations

- **B0505S-1WR3**: SIP-4 through-hole package. JLCPCB SMT assembly does not support THT by default; may require hand-soldering or their THT service add-on.
- **RP2040**: Currently a placeholder (`has_part_removed`). Not assembled; intended as a future daughter-board or direct placement once atopile trait resolution is fixed.
- **100 MOhm resistor (TIA range 0)**: 0805 package, 5% tolerance. Verify JLCPCB stock for this value; high-value resistors may have limited availability.
- **20 MOhm / 10 MOhm resistors**: 0603 package. Check extended library availability.
- **Precision 0.1% resistors (10k)**: Used in DAC subtractor. Typically extended parts on JLCPCB.
- **Dual-supply operation**: The design uses +5V / -5V (via TPS60403) for analog op-amps. Ensure correct polarity marking in assembly files.

### Estimated Extended Part Surcharge

With ~12 unique extended parts at ~$3 each = ~$36 per assembly run (one-time, not per board).

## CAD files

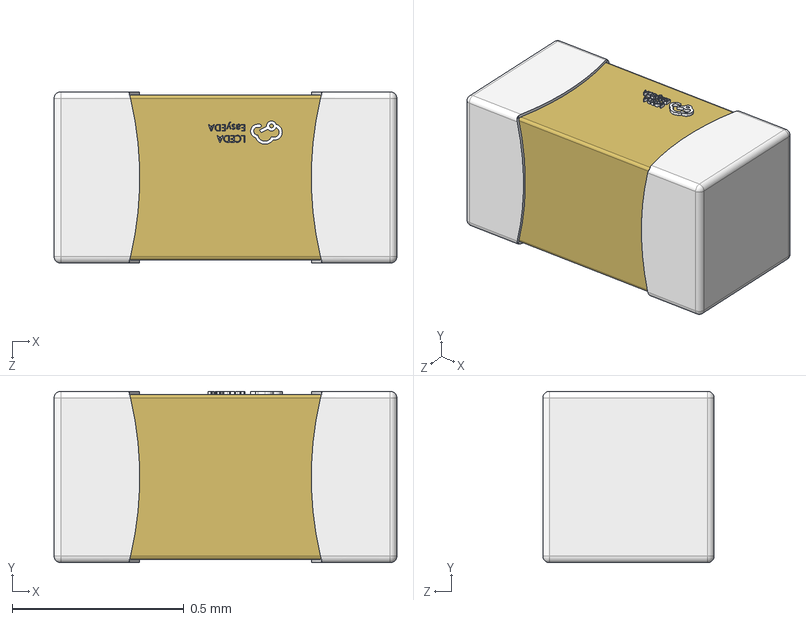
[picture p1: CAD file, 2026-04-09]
parts/CCTC_TCC0402C0G100J500AT/C0402_L1.0-W0.5-H0.5.step
1.00 x 0.5 x 0.5 mm

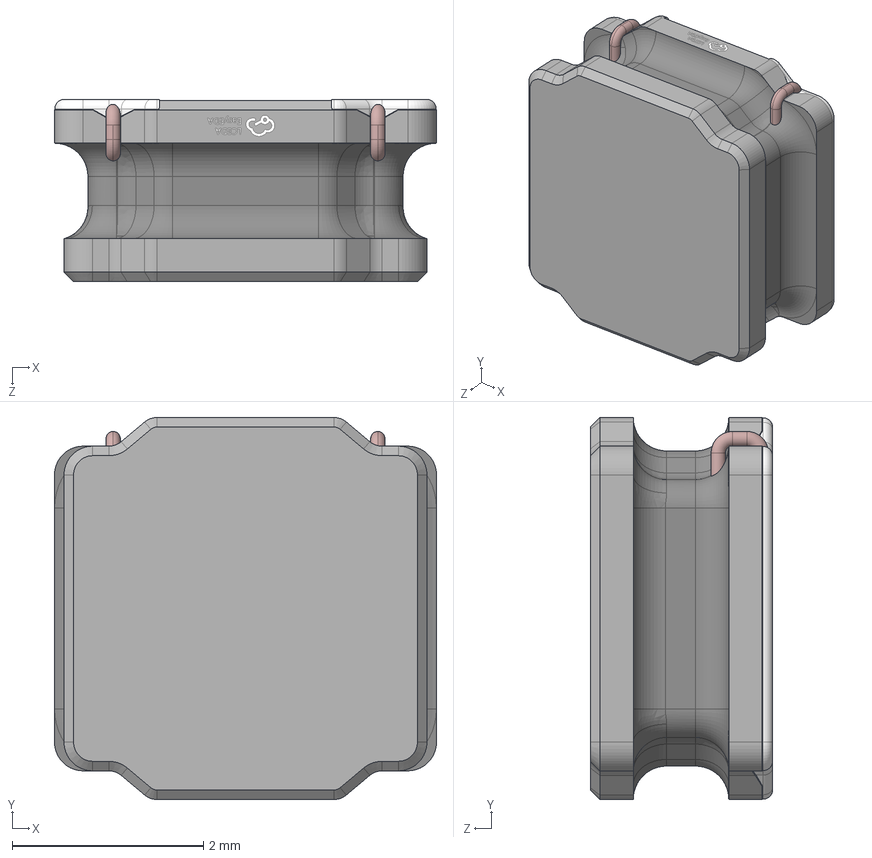
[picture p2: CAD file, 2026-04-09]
parts/cjiang_FHD4020S_1R0MT/IND-SMD_L4.0-W4.0-H1.9.STEP
4.00 x 4.00 x 1.91 mm

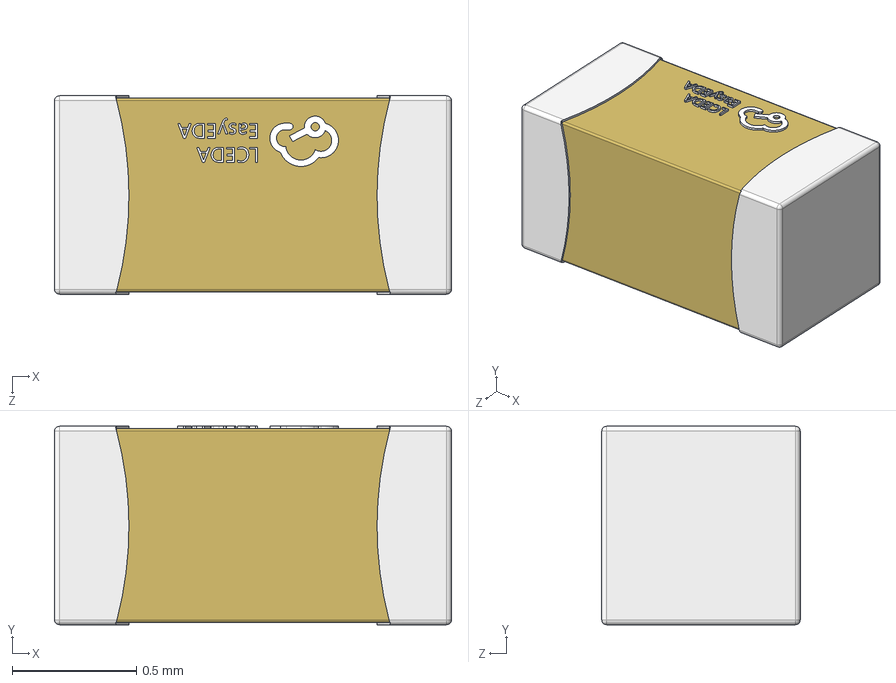
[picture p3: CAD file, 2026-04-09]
parts/FH_0603B472K500NT/C0603_L1.6-W0.8-H0.8.step
1.60 x 0.8 x 0.8 mm

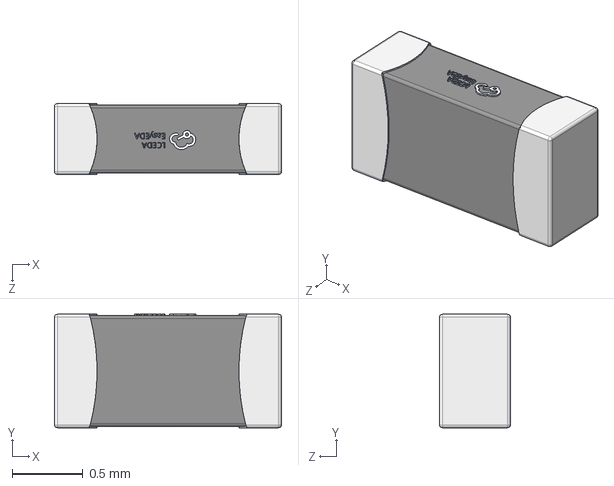
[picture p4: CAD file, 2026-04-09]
parts/FH_CMH160808B4R7MT/L0603_L1.6-W0.8-H0.5_BEAD.step
1.60 x 0.8 x 0.5 mm

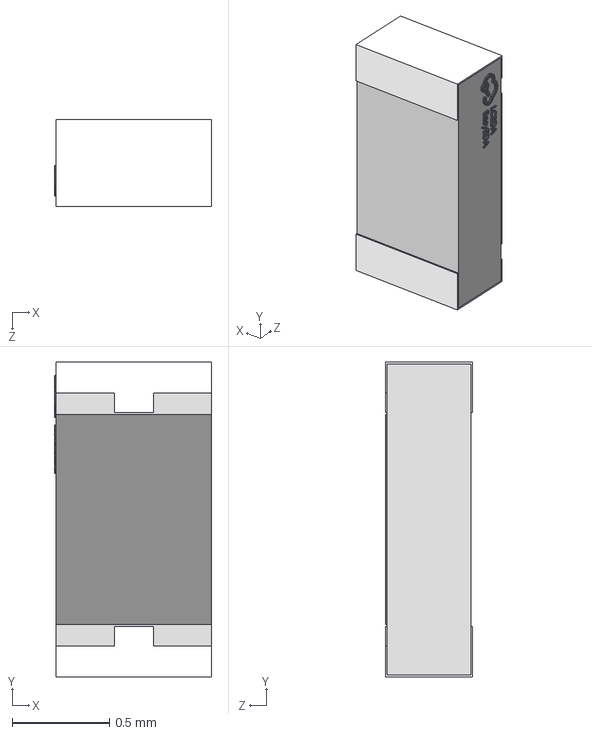
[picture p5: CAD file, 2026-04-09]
parts/FOJAN_FRG0603F2005TS/R0603.STEP
0.81 x 1.62 x 0.45 mm

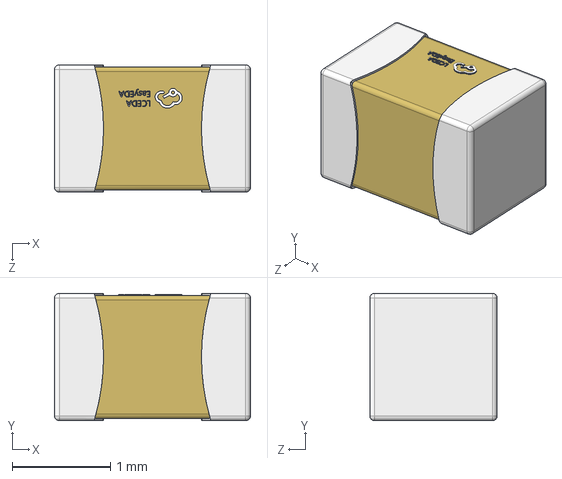
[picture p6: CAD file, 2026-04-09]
parts/Samsung_Electro_Mechanics_CL21A106KAYNNNE/C0805_L2.0-W1.3-H1.3.step
2.00 x 1.30 x 1.30 mm

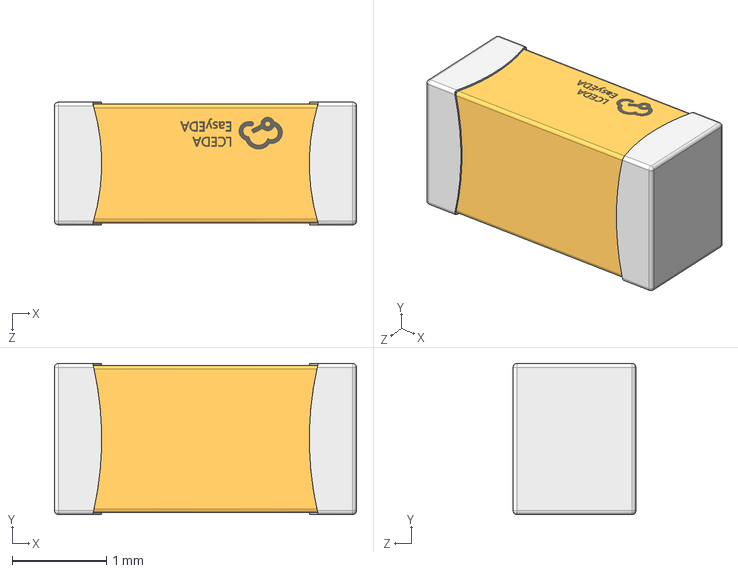
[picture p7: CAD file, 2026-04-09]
parts/Samsung_Electro_Mechanics_CL31A107MQHNNNE/C1206_L3.2-W1.6-H1.3.step
3.20 x 1.60 x 1.30 mm

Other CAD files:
parts/Murata_Electronics_BLM15AG601SN1D/L0402_L1.0-W0.5-H0.5_BEAD.step
parts/STE_R06B1B271KN0B0S0N0/CAP-TH_L6.0-W2.5-P5.0.step
parts/Texas_Instruments_TPS60403DBVR/SOT-23-5_L2.9-W1.6-H1.1-LS2.8-P0.95.step
parts/UNI_ROYAL_0402WGF1200TCE/R0402_L1.0-W0.5-H0.4.step
parts/YAGEO_RC0805JR_07100ML/R0805_L2.0-W1.3-H0.6.step

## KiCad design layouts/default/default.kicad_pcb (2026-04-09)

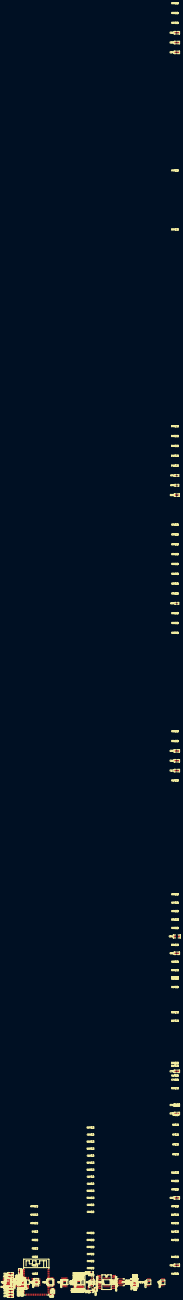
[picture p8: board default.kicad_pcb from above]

Board: 2 copper layers, 218 parts (0 on the bottom side), 117 nets.

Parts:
C1, C16, C17, C19, C20, C43, C47, C48, C54, C55, C56, C63, C70, C71, C73, C82: 10µF ±10%; C0805
C2, C3, C6, C8, C9, C11, C13, C14, C15, C18, C21, C22, C27, C28, C30, C40, C41, C44, C46, C53, C57, C58, C59, C62, C64, C65, C66, C72, C74, C75, C76, C79, C83, C85, C89, C90, C91, C92, C93, C94, C95, C96, C97, C98, C99: 100nF ±10%; C0402
C4, C5, C45, C60, C61, C68, C69, C86, C87, C88: 1µF ±10%; C0402
C7, C12, C29: 10µF ±20%; C0402
C10, C67: 1nF ±10%; C0402
C23, C31: 10pF ±5%; C0402
C24, C25: 4.7nF ±10%; C0603
C26: 10µF ±10%; C0603
C32, C33: 4pF ±5%; C0402
C34, C35: 47pF ±5%; C0402
C36, C37: 470pF ±10%; C0402
C38, C39: 4.7nF ±10%; C0402
C42: 2.2µF ±20%; C0402
C49, C50, C51, C52: 22µF ±20%; C0805
C77, C78, C80, C81: 100nF ±10%; C0603
C84: 100µF ±20%; C1206
L1, L2: L 4.7µH ±20%; L0603
L3: L 1µH ±20%; IND-SMD_L4.0-W4.0
R1, R11, R12, R13, R16, R25, R26, R27, R28, R29, R30, R33, R34, R35, R36, R47, R48, R49, R50, R51, R52, R53, R54, R55, R56, R57, R58, R59, R60, R61, R62, R63, R65, R66, R72, R73, R80, R81, R82, R83, R84, R85: 10kΩ ±1%; R0402
R2, R3, R4, R5, R6, R7, R8, R9, R15, R38, R64: 1kΩ ±1%; R0402
R10: 10Ω ±1%; R0402
R14: 100kΩ ±1%; R0402
R17, R18, R19, R20: 10kΩ ±0.1%; R0402
R21, R22, R32: L {ℝ+}H; L0402
R23, R70: 15.8kΩ ±1%; R0402
R24, R71: 8.87kΩ ±1%; R0402
R31, R78, R87: 100Ω ±1%; R0402
R37: 10MΩ ±1%; R0603
R39: 100MΩ ±5%; R0805
R40: 20MΩ ±1%; R0603
R41: 2MΩ ±1%; R0603
R42: 200kΩ ±1%; R0402
R43: 20kΩ ±1%; R0402
R44: 2kΩ ±1%; R0402
R45: 200Ω ±1%; R0402
R46: 20Ω ±1%; R0402
R67: 102kΩ ±1%; R0402
R68: 11.3kΩ ±1%; R0402
R69: 1MΩ ±1%; R0402
R74, R75, R76, R77: 49.9Ω ±1%; R0402
R79: 8.06kΩ ±1%; R0402
R86: 120Ω ±1%; R0402
SW1, SW2: KEY-SMD_4P-L4.2-W3.2-P2.20-LS4.6
U1: TSSOP-28_L9.7-W4.4-P0.65-LS6.4-BL
U2: MSOP-10_L3.0-W3.0-P0.50-LS4.9-BL
U3, U11, U14, U16, U22, U23: VSSOP-10_L3.0-W3.0-P0.50-LS4.9-BL
U4: PWRM-TH_B0505S-1WR3
U5: SOIC-16_L10.3-W7.4-P1.27-LS10.3-BL
U6, U12, U15, U19: TSSOP-14_L5.0-W4.4-P0.65-LS6.4-BL
U7: TSSOP-24_L7.8-W4.4-P0.65-LS6.4-BL
U8: WIRELM-SMD_ESP32-S3-WROOM-1
U9: VSON-14_L4.0-W3.0-P0.50-BL-EP_TI_DSJ
U10, U13, U20: SOT-23-5_L3.0-W1.7-P0.95-LS2.8-BL
U17, U18: TQFN-20_L5.0-W5.0-P0.65-TL-EP3.1
U21: SOP-16_L9.9-W3.9-P1.27-LS6.0-BL
U24, U25: SSOP-16_L5.3-W3.4-P0.65-LS5.2
U26: SOIC-8_L4.9-W3.9-P1.27-LS6.0-BL
U27: TSSOP-16_L5.0-W4.4-P0.65-LS6.4-BL

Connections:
2: R2.2, U1.2
3: R3.2, U1.3
4: R4.2, U1.4
8: R38.2, U1.8
16: R82.2, U24.16
DATA_N: U8.13, U26.4
DATA_P: R87.1, U8.14
ENA: R27.1, U17.10
ENB: R28.1, U17.16
PG: R69.1, U9.14
RESET: R72.2, U1.19
RS: R85.1, U26.8
SCL: R11.1, R33.2, R34.2, R48.1, U2.7, U5.6, U5.11, U7.5, U21.13
SDA: R12.1, R35.2, R36.2, R56.1, U2.8, U5.5, U5.12, U7.4, U21.14
SYNC_PDWN: R73.2, U1.18
TXD: U8.11, U26.1
_inductor_1-8: L3.1, U9.8, U9.9
_inductor_2-6: L3.2, U9.6, U9.7
a_inverting: R17.2, R18.2, U12.2
a_inverting_N: R7.1, U14.4, U15.1, U15.2
a_noninverting: R18.1, U6.3, U12.1
bank_switch-enables[1]-7: R26.1, U16.7
c_bw_0-power-hv: C32.1, R39.1, U17.6
c_bw_1-power-hv: C33.1, R40.1, U17.7
c_bw_2-power-hv: C34.1, R41.1, U17.8
c_bw_3-power-hv: C35.1, R42.1, U17.9
c_bw_4-power-hv: C36.1, R43.1, U18.6
c_bw_5-power-hv: C37.1, R44.1, U18.7
c_bw_6-power-hv: C38.1, R45.1, U18.8
c_bw_7-power-hv: C39.1, R46.1, U18.9
c_en-power-hv: C45.1, R66.2, SW2.3, SW2.4, U8.3
can_h: R86.1, U26.7
can_l: R86.2, U26.6
ch0-7: R81.2, U24.7
ch0-7-1: R83.2, U25.7
ch0-16: R84.2, U25.16
ch0-a_noninverting: R19.2, R20.1, U12.3
common_a: U16.2, U18.5
comp_c0-power-hv: C23.1, R78.1, U22.3
comp_c1-power-hv: C66.1, R79.1, U22.9
comp_c2-power-hv: C67.1, R80.1, U23.3
comp_select[0]-line: U22.5, U22.7
current_sense_N: R3.1, R5.2, R75.1
current_sense_P: R2.1, R6.2, R74.1
dac_raw_out: R15.1, U2.10, U11.2
decoupling_capacitor_in[0]-power-hv: C24.1, L1.1, U4.2
decoupling_capacitor_out-power-hv: C26.1, L2.1, U4.4
feedback_divider-ref_out-hv: R23.2, R24.1, U13.4
feedback_divider-ref_out-hv-1: R67.2, R68.1, U9.3
feedback_divider-ref_out-hv-2: R70.2, R71.1, U10.4
feedback_node_P: R8.1, U3.10, U16.3, U19.2
filter_cap-power-lv-1_N: C89.2, R77.2, U21.4
filter_cap-power-lv_N: C6.2, R75.2, U21.2
filter_cap-power-output_P: C89.1, R76.2, U21.5
filter_capacitor-power-hv: C14.1, R15.2, R17.1, U11.3
filter_switch-enables[1]-7: R16.1, U11.7
flying_cap-power-hv: C86.1, U20.5
gpio[11]-line: U3.5, U3.7
gpio[17]-line: R1.2, U1.16
guard_output-b_inverting: U15.6, U15.7
host_in[2]-line: U25.4, U27.15
host_spi-MISO: U8.21, U25.5
host_spi-MOSI: U8.19, U25.3
host_spi-SCLK: U8.20, U25.2
hv: C1.1, C2.1, C7.1, C8.1, C9.1, C11.1, C12.1, C15.1, C16.1, C17.1, C18.1, C20.1, C22.1, C28.1, C29.1, C30.1, C40.1, C62.1, C63.1, C64.1, C65.1, C68.1, C71.1, C72.1, C73.1, C74.1, C75.1, C76.1, C79.1, C82.1, C83.1, C92.1, C93.1, C95.1, C97.1, L2.2, R14.2, R21.2, R27.2, R29.2, R34.1, R36.1, R82.1, R84.1, U1.1, U1.24, U2.1, U3.1, U5.14, U6.4, U11.1, U12.4, U13.1, U13.3, U14.1, U15.4, U16.1, U17.13, U18.13, U19.4, U22.1, U23.1, U24.15, U25.15
i2c_mux-reset-nRESET: R47.1, U7.3
i2cs[1]-SCL: R49.1, U7.7
i2cs[1]-SDA: R57.1, U7.6
i2cs[2]-SCL: R50.1, U7.9
i2cs[2]-SDA: R58.1, U7.8
i2cs[3]-SCL: R51.1, U7.11
i2cs[3]-SDA: R59.1, U7.10
i2cs[4]-SCL: R52.1, U7.14
i2cs[4]-SDA: R60.1, U7.13
i2cs[5]-SCL: R53.1, U7.16
i2cs[5]-SDA: R61.1, U7.15
i2cs[6]-SCL: R54.1, U7.18
i2cs[6]-SDA: R62.1, U7.17
i2cs[7]-SCL: R55.1, U7.20
i2cs[7]-SDA: R63.1, U7.19
input_guard_cap-power-hv: C31.1, R37.2, U15.3, U15.5
io[15]-line: R64.1, U8.8
io[17]-line: R31.1, U8.10
io[21]-line: U8.23, U27.1
io[38]-line: U8.31, U27.2
io[39]-line: U8.32, U27.3
lv: C23.2, C66.2, C67.2, R10.1, R78.2, R79.2, R80.2, U6.1
lv_N: C1.2, C2.2, C3.2, C4.2, C5.2, C7.2, C8.2, C9.2, C10.2, C11.2, C12.2, C13.2, C14.2, C15.2, C16.2, C17.2, C18.2, C20.2, C22.2, C26.2, C28.2, C29.2, C30.2, C31.2, C40.2, C41.2, C42.2, C43.2, C44.2, C45.2, C46.2, C54.2, C57.2, C61.2, C62.2, C63.2, C64.2, C65.2, C68.2, C69.2, C70.2, C71.2, C72.2, C73.2, C74.2, C75.2, C76.2, C77.2, C78.2, C79.2, C80.2, C81.2, C82.2, C83.2, C84.2, C85.2, C90.2, C91.2, C92.2, C93.2, C95.2, C96.2, C97.2, C98.2, C99.2, R5.1, R9.2, R13.2, R16.2, R20.2, R24.2, R25.2, R26.2, R28.2, R30.2, R71.2, R85.2, SW1.1, SW1.2, SW2.1, SW2.2, U1.5, U1.6, U1.7, U1.17, U1.25, U1.27, U2.5, U2.6, U3.6, U4.3, U5.9, U5.16, U6.11, U7.1, U7.2, U7.12, U7.21, U8.1, U8.40, U8.41, U11.6, U12.11, U13.2, U14.6, U15.11, U16.6, U17.3, U18.3, U19.3, U19.11, U21.7, U21.8, U21.9, U22.6, U23.6, U24.14, U25.8, U25.14, U26.2, U27.5, U27.8
lv_P: C32.2, C33.2, C34.2, C35.2, C36.2, C37.2, C38.2, C39.2, R6.1, R39.2, R40.2, R41.2, R42.2, R43.2, R44.2, R45.2, R46.2, U14.2, U19.1
mux_b-enable_a-ENA: R29.1, U18.10
mux_b-enable_b-ENB: R30.1, U18.16
nLDAC: R13.1, U2.4
nRESET: R14.1, U2.3
negative_charge_pump_capacitor-power-hv: C77.1, U17.4, U17.21
negative_charge_pump_capacitor-power-hv-1: C80.1, U18.4, U18.21
output: R65.2, SW1.3, SW1.4, U8.27
output_P: C6.1, R74.2, U21.3
positive_charge_pump_capacitor-power-hv: C78.1, U17.2
positive_charge_pump_capacitor-power-hv-1: C81.1, U18.2
power_5v-hv: C19.1, C21.1, C25.1, C27.1, C49.1, C50.1, C51.1, C52.1, C55.1, C58.1, C60.1, C87.1, C94.1, L1.2, R33.1, R35.1, R67.1, R69.2, R81.1, U5.3, U9.4, U9.5, U10.1, U10.3, U20.1, U24.1
power_in-hv: C47.1, C48.1, U9.10, U9.11
power_in-lv: C47.2, C48.2, U9.2, U9.15
power_in_a_capacitor-power-hv: C53.1, U9.1, U9.12, U9.13
power_neg-hv: C19.2, C21.2, C24.2, C25.2, C27.2, C49.2, C50.2, C51.2, C52.2, C55.2, C56.1, C58.2, C59.1, C60.2, C87.2, C88.1, C94.2, R68.2, U4.1, U5.1, U5.7, U10.2, U20.2, U24.8
power_neg-lv: C56.2, C59.2, C86.2, C88.2, U20.3
sense_inputs[1]_N: R7.2, R38.1, R77.1
sense_inputs[1]_P: R4.1, R8.2, R76.1
snubber_capacitor-power-hv: C10.1, R10.2, U3.2
sw-enables[1]-7: R25.1, U14.7
switches_nc[0]-common_a: U16.4, U17.5
switches_no[0]-2: U6.2, U14.3, U22.2, U22.10, U23.2
touch[8]-SDA: U7.23, U8.12
touch[9]-SCL: U7.22, U8.17
touch[10]-line: U8.18, U27.4
vbg_cap-power-hv: C91.1, U21.6
vref_cap-power-hv: C13.1, R19.1, U2.9
wifi_bypass_cap-power-hv: C3.1, C4.1, C5.1, C41.1, C42.1, C43.1, C44.1, C46.1, C54.1, C57.1, C61.1, C69.1, C70.1, C84.1, C85.1, C90.1, C96.1, C98.1, C99.1, R1.1, R11.2, R12.2, R21.1, R23.1, R32.1, R32.2, R47.2, R48.2, R49.2, R50.2, R51.2, R52.2, R53.2, R54.2, R55.2, R56.2, R57.2, R58.2, R59.2, R60.2, R61.2, R62.2, R63.2, R65.1, R66.1, R70.1, R72.1, R73.1, R83.1, U1.26, U2.2, U7.24, U8.2, U10.5, U13.5, U21.1, U21.15, U21.16, U25.1, U26.3, U27.6, U27.16

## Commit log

2026-04-09 feat: V0.4 development snapshot of modular multichannel potentiostat
    Initial development snapshot of atostat, a modular multichannel
    potentiostat/bipotentiostat designed in atopile targeting 10nA-1A
    current range with +-2V compliance voltage.
    Architecture:
    - 19 library modules covering analog frontend (control amplifier,
    switched-gain TIA, reference buffer, EIS excitation), power supply
    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
    [C0402_L1.0-W0.5-H0.5.step, C0603_L1.6-W0.8-H0.8.step, C0805_L2.0-W1.3-H1.3.step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]
2026-04-09 feat(v0.4): resolve B0505S false short, replace all placeholders, add SPI CS demux
    Remove the anti-EMI Y-capacitor from the B0505S isolated DC-DC driver
    to eliminate false short-circuit detection across the galvanic isolation
    barrier. This unblocks replacement of all remaining component placeholders:
    ISO7741 digital isolator (real driver), ferrite beads (Murata BLM15AG601SN1D,
    LCSC C76884), and adds SPI chip-select demux architecture (TI SN74HC138PWR)
    for multi-channel gateway-to-RP2040 addressing.
    - lib/b0505s_no_ycap.ato: custom B0505S driver without Y-cap
    - lib/galvanic_isolator.ato: real ISO7741, real ferrite beads, new DC-DC
    - lib/spi_isolator.ato: real ISO7741, updated interface names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
2026-04-09 feat(v0.4): add channel 1 wiring, SPI power separation, and 74HC138 symbols
    Wire second potentiostat channel (ch1) with full power/I2C/SPI/electrode
    connections. Separate host-side SPI isolator power to 3.3V rail for proper
    level matching. Add 74HC138 KiCad symbol and footprint for CS demux.
    Document TPS60403 solver hang blocking isolated -5V rail implementation.
    Build-verified: ato build passed all 18 stages with 0 errors.
2026-04-09 build(ato): add PCB layout and auto-picked component packages from first successful ato build
    Add KiCad PCB layout (default.kicad_pcb), footprint library table,
    and two auto-generated component packages:
    - Murata BLM15AG601SN1D ferrite bead
    - UNI-ROYAL 0402WGF1200TCE 120 ohm CAN termination resistor
    [L0402_L1.0-W0.5-H0.5_BEAD.step, R0402_L1.0-W0.5-H0.4.step, default.kicad_pcb]
2026-04-09 docs: add V0.4 architecture overview, BOM summary, and rewrite README
    Complete documentation refresh for V0.4 milestone:
    - README.md: rewrite with current specs, module listing, build instructions, known issues
    - docs/ARCHITECTURE.md: block diagram, signal flow, isolation boundary, comm topology, power domains, component rationale
    - docs/BOM_SUMMARY.md: key ICs table, passive counts, JLCPCB assembly notes and extended-part surcharge estimate
    - .github/workflows/build.yml: switch trigger from push/pull_request to workflow_dispatch to avoid 40-min CI runs on every push
